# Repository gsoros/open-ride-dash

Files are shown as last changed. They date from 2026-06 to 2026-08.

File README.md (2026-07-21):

# OpenRideDash

OpenRideDash is open-source firmware for an ESP32-C3 based e-bike dashboard. It provides a compact ride display, CAN data integration, BLE and Wi-Fi connectivity, OTA updates, Shell diagnostics, and keypad-driven menus on a 240x240 ST7789 display. Currently the Bafang M560 mid-drive controller is supported.

## Features

- ESP32-C3 Super Mini support
- ST7789 240x240 color display driver
- CAN bus data integration for e-bike metrics
- BLE cycling services, API bridge for the mobile app
- Wi-Fi connectivity and OTA firmware updates
- Serial over WiFi access for diagnostics and command handling
- Custom keypad/menu navigation
- Task-based architecture for modular firmware components
- Rolling firmware bootloader support via custom bootloader replacement

## Hardware

- ESP32-C3 development board (`esp32-c3-devkitm-1`)
- ST7789 240x240 display
- CAN bus interface
- Keypad 

## Software Stack

- PlatformIO with Arduino framework
- ESP32 platform version `6.13.0`
- Arduino GFX library
- Patched MPU9250 dependency 
- `ACAN_ESP32` for CAN support
- `OneButton` for keypad/button handling

## Repository Structure

- platformio.ini — build and environment configuration
- src — main firmware source
  - main.cpp — system initialization and task startup
  - `drivers/` — display and hardware drivers
  - `model/` — shared state model
  - `tasks/` — modular runtime components (Wi-Fi, OTA, WifiSerial, CAN, display, keypad, alarm)
- include — shared headers, config, and font assets
- bootloader — bootloader binary, compiled from `esp-idf/components/esptool_py/bootloader`
- ota_nofs_4MB.csv — partition table for rollback-enabled OTA
- version, version.py, build_info.py — version/build metadata injection

## Build & Flash

1. Install PlatformIO
2. Connect the ESP32-C3 board
3. Use the `devel` environment for development builds:
   - `pio run -e devel`
   - `pio run -e devel -t upload`
4. Use `prod` for production builds
5. OTA builds are available via `develOTA` and `prodOTA`

## Notes

- `loop()` is intentionally empty; tasks are scheduled via FreeRTOS.
- The project applies a custom bootloader replacement during the build.
- The display driver uses multiple canvas layers and animated page transitions.

## Companion App

[**Wattson**](https://github.com/gsoros/wattson) is the companion mobile app for OpenRideDash. Built with Flutter, it connects to the dash via BLE to display live telemetry, record rides with GPS, and export GPX data — all local-first with no cloud dependency.

## License

This project is licensed under the terms of the included LICENSE.

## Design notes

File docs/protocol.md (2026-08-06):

# ORD Dash — BLE NUS Text API Protocol

Authoritative reference for the Nordic UART Service (NUS) command/reply protocol
used by the OpenRideDash (ORD) e-bike display.

---

## 1. Transport

### NUS Service

| Role | UUID | Property |
|---|---|---|
| NUS Service | `6e400001-b5a3-f393-e0a9-e50e24dcca9e` | — |
| RX (phone → device) | `6e400002-b5a3-f393-e0a9-e50e24dcca9e` | **WRITE** (with response) |
| TX (device → phone) | `6e400003-b5a3-f393-e0a9-e50e24dcca9e` | **NOTIFY** only (no READ) |

### RX (phone → device)

The phone writes a UTF-8 command string (max 250 bytes) to the RX characteristic.
The device processes the command asynchronously and enqueues a reply on the TX
characteristic.

### TX (device → phone) — Fragmentation

Replies are sent as one or more BLE notifications. The first notification carries
a **2-byte big-endian total-length prefix**; subsequent notifications are raw
continuation data.

```
First notification:  [len_hi][len_lo][payload bytes 0..N-1]
Subsequent:          [payload bytes N..M-1]
                     ...
```

- `len_hi` = `(total >> 8) & 0xFF`
- `len_lo` = `total & 0xFF`
- `total` = total number of payload bytes (excluding the 2-byte prefix)
- Chunk size = `min(MTU, 247) - 3` (ATT overhead). At MTU=247, each notification
  carries 244 bytes of payload.
- 10 ms delay between multi-chunk frames.

**Phone reassembly rule:** Read the first 2 bytes as big-endian total length,
then accumulate notifications until that many bytes have been received. The first
notification includes the 2-byte prefix (so first payload = `first.length - 2`).

---

## 2. Command Format

Commands are UTF-8 strings sent to the NUS RX characteristic. The format is:

```
<command>[ <args>]
```

- `<command>` — a single word (max 32 chars), case-sensitive.
- `<args>` — optional, space-delimited tokens following the command name.
- Max total length: 250 bytes (hardware limit).
- Trailing `\r` / `\n` are stripped by the device.

### Argument structure

Commands follow a consistent pattern:

| Pattern | Example |
|---|---|
| `cmd` (bare) | `hostname` — get current value |
| `cmd <value>` | `hostname ord-c3` — set value |
| `cmd <subcommand>` | `ble on`, `ble status` — subcommand action |
| `cmd <subcommand> <value>` | `wifi ssid MyNetwork` — subcommand with value |

Boolean values use the strings `on` (true) and `off` (false), as returned by
`Util::boolToString()`.

---

## 3. Reply Format

Every command produces a reply with the following wire format:

```
API [<command>[ <args>]] (<code>) <data>
```

| Part | Description |
|---|---|
| `API [` | Literal prefix |
| `<command>` | The command name (e.g. `hostname`, `ble`) |
| ` ` | Space separator (present only if args follow) |
| `<args>` | The arguments as received by the handler |
| `] (` | Literal separator |
| `<code>` | Reply code string (see below) |
| `) ` | Literal separator |
| `<data>` | Reply payload (text, may be empty) |

### Reply codes

| Code | Enum value | Meaning |
|---|---|---|
| `Success` | `Code::Success` | Command executed successfully |
| `Unknown Command` | `Code::UnknownCommand` | Command name not recognised |
| `Invalid Arguments` | `Code::InvalidArgs` | Arguments are malformed or out of range |
| `Execution Error` | `Code::ExecutionError` | Command failed at runtime |

### Examples

```
API [hostname] (Success) ord-c3
API [ble status] (Success) enabled: on, connected: true
API [wifi] (Success) sta: on, ap: on, ssid: myNetwork, password: myPassword
API [battery] (Success) 720
API [v] (Success) ord-v0.1.0-42-gabc1234
API [ble bogus] (Invalid Arguments) Usage: ble[ on|off|toggle|status]
API [nonexistent] (Unknown Command) 'nonexistent' is a mystery
```

---

## 4. Commands

### 4.1 `v` — Version

| | |
|---|---|
| **Get** | `v` |
| **Reply data** | Build info string (`whoami`) |
| **Example** | `API [v] (Success) ord-v0.1.0-42-gabc1234` |

### 4.2 `help` — Help

| | |
|---|---|
| **List** | `help` |
| **Detail** | `help <command>` |
| **Reply data (list)** | `Commands: v, help, restart, ...` |
| **Reply data (detail)** | `<command>: <helpText>` |
| **Example** | `API [help] (Success) Commands: v, help, restart, ...` |

### 4.3 `restart` — Restart

| | |
|---|---|
| **Execute** | `restart` |
| **Reply** | (never returns — device reboots immediately) |

### 4.4 `hostname` — Hostname

| | |
|---|---|
| **Get** | `hostname` |
| **Set** | `hostname <name>` |
| **Reply data (get)** | Current hostname string |
| **Reply data (set)** | New hostname string (may be trimmed) |
| **Example** | `API [hostname] (Success) ord-c3` |

### 4.5 `battery` — Battery capacity

| | |
|---|---|
| **Get** | `battery` |
| **Set** | `battery <capacity>` |
| **Args** | `<capacity>` — uint16, watt-hours |
| **Reply data (get)** | Current capacity in Wh |
| **Reply data (set)** | `Battery capacity set to <N> Wh` |
| **Example** | `API [battery] (Success) 720` |

### 4.6 `ble` — BLE radio

| | |
|---|---|
| **Status** | `ble` or `ble status` |
| **Enable** | `ble on` — **triggers reboot** |
| **Disable** | `ble off` — **triggers reboot** |
| **Toggle** | `ble toggle` — **triggers reboot** |
| **Reply data (status)** | `enabled: <on|off>, connected: <on|off>` |
| **Reply data (on/off/toggle)** | `<on|off>` — new state after applying change |
| **Example** | `API [ble] (Success) enabled: on, connected: true` |

### 4.7 `wifi` — WiFi

| | |
|---|---|
| **Summary** | `wifi` |
| **Enable STA** | `wifi on` — **triggers reboot** |
| **Disable STA** | `wifi off` — **triggers reboot** |
| **Toggle STA** | `wifi toggle` — **triggers reboot** |
| **Get SSID** | `wifi ssid` |
| **Set SSID** | `wifi ssid <name>` — restarts STA |
| **Get password** | `wifi password` |
| **Set password** | `wifi password <pw>` — restarts STA |
| **Get AP state** | `wifi ap` |
| **Enable AP** | `wifi ap on` — **triggers reboot** |
| **Disable AP** | `wifi ap off` — **triggers reboot** |
| **Toggle AP** | `wifi ap toggle` — **triggers reboot** |
| **Connection status** | `wifi status` |
| **Reply data (summary)** | `sta: <on|off>, ap: <on|off>, ssid: <name>, password: <pw>` |
| **Reply data (on/off/toggle)** | `<on|off>` — new state |
| **Reply data (ssid/password)** | Current value string |
| **Reply data (status)** | `sta: <connected|disconnected>, ap_clients: <N>` |
| **Example** | `API [wifi] (Success) sta: on, ap: on, ssid: myNetwork, password: myPassword` |

### 4.8 `sim` — Simulator (only if `FEATURE_SIM` is compiled)

| | |
|---|---|
| **Status** | `sim` |
| **Enable** | `sim on` |
| **Disable** | `sim off` |
| **Reply data** | `sim <on|off>` |
| **Example** | `API [sim] (Success) sim on` |

### 4.9 `state` — JSON telemetry snapshot

| | |
|---|---|
| **Get** | `state` |
| **Reply data** | JSON object with current telemetry values |
| **Example** | `API [state] (Success) {"speed":0.00,"pas":0,"torque":750,...}` |

### 4.10 `echo` — WifiSerial echo (only if WifiSerial is active)

| | |
|---|---|
| **Enable** | `echo on` |
| **Disable** | `echo off` |
| **Reply data** | `WifiSerial echo <on|off>` |

### 4.11 `key` — Simulate key press

| | |
|---|---|
| **Execute** | `key <up|down|upLong|downLong|power|menu>` |
| **Reply** | (triggers UI event, no meaningful data) |

### 4.12 `arm` / `disarm` — Motion alarm

| | |
|---|---|
| **Arm** | `arm` |
| **Disarm** | `disarm` |
| **Reply** | (arms/disarms MPU motion sensor) |

### 4.13 `nullpointer` — Crash test

| | |
|---|---|
| **Execute** | `nullpointer` |
| **Reply** | (crashes the device intentionally) |

### 4.14 `torquelog` — Torque sensor ring buffer dump

| | |
|---|---|
| **Get** | `torquelog` |
| **Reply data** | Header line + up to 20 torque samples |
| **Example** | `API [torquelog] (Success) torquelog: 154 samples` then `T:12345 R:1250 O:500 C:80 S:5 ST:5B U2:0\n...` |

Dumps the most recent torque sensor samples from the internal ring buffer.
Each sample line format: `T:<timestamp_ms> R:<rawTorque> O:<offsetTorque> C:<cadence> S:<sequence> ST:<status> U2:<unknown2>`.
Always present (no feature flag needed).

### 4.15 `ema` — EMA smoothing bypass

| | |
|---|---|
| **Status** | `ema` |
| **Enable** | `ema on` |
| **Disable** | `ema off` |
| **Reply data** | `ema <on|off>` |
| **Example** | `API [ema] (Success) ema on` |

Controls the exponential moving average filters applied to human power, SoC,
and range. When OFF, raw (unfiltered) values are returned, making torque drops
easier to detect. Always present.

---

## 5. Boolean representation

All boolean values use the strings `on` (true) and `off` (false), as defined by
`Util::boolToString()`:

```cpp
static const char* boolToString(bool value) {
    return value ? "on" : "off";
}
```

Parsing helpers:

```cpp
static bool isStrBoolOn(const char* str)  { return strcmp(str, "on") == 0; }
static bool isStrBoolOff(const char* str) { return strcmp(str, "off") == 0; }
static bool parseBoolValue(const char* args, bool* value);
```

---

## 6. CTS Telemetry Payload

The CTS custom service (`f6333d96-74c0-462d-b92d-5750a2283429`) sends a 14-byte
little-endian binary payload on the telemetry characteristic
(`5ee460d2-75a3-41ac-9034-2b2d435bb549`, NOTIFY + READ).

| Byte | Field | Type | Scale |
|---|---|---|---|
| 0 | Version/flags | `uint8` | `0x01` |
| 1–2 | Speed | `uint16` LE | km/h × 100 |
| 3–4 | Battery voltage | `uint16` LE | V × 100 |
| 5–6 | Battery current | `uint16` LE | A × 100 (unsigned — no regen) |
| 7 | State of charge | `uint8` | % |
| 8–9 | Range | `uint16` LE | km × 100 |
| 10 | PAS level | `int8` | −1 walk, 0 off, 1–5 |
| 11–12 | Human power | `uint16` LE | W × 10 |
| 13 | Cadence | `uint8` | RPM |

Forward-compat: ignore trailing bytes if `length > 14`; reject unknown version.

---

## 7. CTS HR Write Characteristic

The CTS service also exposes a write characteristic for receiving heart rate data
from the phone:

| UUID | Property | Payload |
|---|---|---|
| `a2c4f7b1-0e3d-4a8c-9b6e-1f2c3d4e5f60` | **WRITE_NR** | Single `uint8` BPM |

The phone writes the current heart rate (BPM) from a connected BLE HRM. The
device stores it in `state.heartRate()` and surfaces it on the display.

---

## 8. Consistency notes

- **Every command** follows the pattern `cmd[ subcmd][ value]`.
- **Every reply** uses the fixed wire format `API [<cmd> <args>] (<code>) <data>`.
- **Every boolean** in reply data uses `on`/`off` from `Util::boolToString()`.
- **Set commands** that change a value return the new value in the reply data.
- **Get commands** (bare command, no args) return the current value.
- **Reboot-triggering commands** (`ble on|off|toggle`, `wifi on|off|toggle`,
  `wifi ap on|off|toggle`) never return a reply — the device restarts immediately.

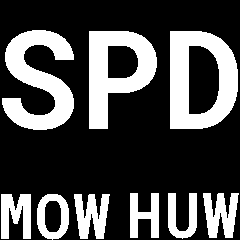
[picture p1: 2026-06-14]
include/display_mockup/metrics_labels_speed-motorPower-human_power.png

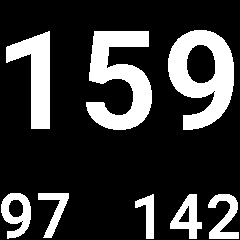
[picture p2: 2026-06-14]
include/display_mockup/metrics_values_heartRate-SOC-range.png

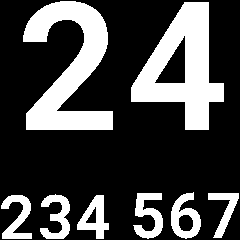
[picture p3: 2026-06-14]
include/display_mockup/metrics_values_speed-motorPower-humanPower.png

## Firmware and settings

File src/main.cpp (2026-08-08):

#include <Arduino.h>

#include "config.h"
#include "model/state.h"
#include "tasks/wifi.h"
#include "tasks/ota.h"
#include "tasks/wifiserial.h"
#include "tasks/system_monitor.h"
#include "tasks/api.h"
#include "tasks/ble.h"
#include "tasks/display.h"
#ifdef FEATURE_SIM
#include "tasks/sim.h"
#endif
#include "tasks/can.h"
#include "tasks/keypad.h"
#include "tasks/alarm.h"

State state;
Api api;
Ble ble;
#ifdef FEATURE_SIM
Sim sim;
#endif
CAN can;
Display display;
Wifi wifi;
OTA ota;
WifiSerial wifiSerial(23);
SystemMonitor systemMonitor;
Keypad keypad;
Alarm alarmTask;  // 'alarm' is a reserved word

void setup() {
    esp_log_level_set("*", ESP_LOG_DEBUG);
    ulong t = millis();

#ifdef FEATURE_SERIAL
    Serial.setTxTimeoutMs(0);
    Serial.setDebugOutput(false);
    Serial.begin(115200);
    while (!Serial && millis() - t < 100) delay(10);
    // delay(100);
#endif

    state.setup();

    api.setup();
    api.taskStart(10.0f, 4096 + 512 + 512);

    ble.setup();
    ble.taskStart(5.0f, 4096);  // Telemetry and Battery updates are rate-limited to 1 Hz, BLEDebug is rate-limited to 20 Hz (50ms)

    display.setup();
    display.taskStart(50.0f, 2048 + 1024 + 512);

    wifi.setup();
    wifi.taskStart(1.0f, 8192);  // AP mode does not work with lower stack size
    wifi.waitForReady();

    if (wifi.isEnabled()) {
        ota.setup();
        ota.taskStart(2.0f, 100.0f, 2048 + 1024 + 512 + 512);
    }

    wifiSerial.setup(wifi.isEnabled());
    wifiSerial.taskStart(10.0f, 1024 + 512 + 512);

#ifdef FEATURE_SIM
    sim.setup();
    sim.taskStart(2.0f, 1024);
#endif

    can.setup();
    can.taskStart(100.0f, 2048 + 512);

    keypad.setup();
    keypad.taskStart(100.0f, 1024 + 512 + 512);

    alarmTask.setup();
    alarmTask.taskStart(100.0f, 1024 + 512 + 512);

    // static Task* tasksToMonitor[] = {&api, &wifi, &ota, &wifiSerial, &display, &can};
    // systemMonitor.setup(tasksToMonitor, sizeof(tasksToMonitor) / sizeof(tasksToMonitor[0]));
    // systemMonitor.taskStart(10.0f, 4096);
}

void loop() {
    vTaskDelete(nullptr);
}

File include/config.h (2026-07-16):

#ifndef CONFIG_H
#define CONFIG_H

#define STR_HELPER(x) #x
#define STR(x) STR_HELPER(x)

#if ORD_BOARD == c3_supermini
#include "pins_c3_supermini.h"
#else
#error "Unsupported board. Please define ORD_BOARD in platformio.ini"
#endif

constexpr const char* DEFAULT_WIFI_SSID = "myNetwork";        // STA SSID
constexpr const char* DEFAULT_WIFI_PASSWORD = "myPassword";   // STA password
constexpr const char* DEFAULT_WIFI_AP_SSID = "OpenRideDash";  // AP SSID

// Fallback AP: if STA doesn't connect within this time, start a passwordless AP
constexpr unsigned long WIFI_STA_TIMEOUT_MS = 60000;
constexpr unsigned char WIFI_AP_CHANNEL = 1;
constexpr unsigned char WIFI_AP_MAX_CONNECTIONS = 2;

#ifndef ORD_NAME
// keep the format, build_info.py will parse this
#define ORD_NAME "OpenRideDash"
#endif

#ifndef ORD_SHORT_NAME
// keep the format, build_info.py will parse this
#define ORD_SHORT_NAME "ord"
#endif

#ifdef BUILDTAG
constexpr const char* DEFAULT_HOSTNAME = ORD_SHORT_NAME "-" STR(BUILDTAG);
#else
constexpr const char* DEFAULT_HOSTNAME = ORD_SHORT_NAME;
#endif

#ifndef TFT_ROTATION
#define TFT_ROTATION 3
#endif

// ST7789 column/row offsets used by Arduino_GFX/Arduino_TFT.
// These are panel/module specific and can be adjusted per module.
// Format: COL_OFFSET1, ROW_OFFSET1, COL_OFFSET2, ROW_OFFSET2
// Defaults are set to values known to work with the maintainer's module.
#ifndef ST7789_COL_OFFSET1
#define ST7789_COL_OFFSET1 0
#endif

#ifndef ST7789_ROW_OFFSET1
#define ST7789_ROW_OFFSET1 0
#endif

#ifndef ST7789_COL_OFFSET2
#define ST7789_COL_OFFSET2 0
#endif

#ifndef ST7789_ROW_OFFSET2
#define ST7789_ROW_OFFSET2 80
#endif

#endif  // CONFIG_H

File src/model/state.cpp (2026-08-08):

#include "state.h"
#include "tasks/api.h"
#include "config.h"
#include "util.h"
#include "util/ema.h"

#include <freertos/FreeRTOS.h>
#include <freertos/semphr.h>

#ifdef FEATURE_SIM
#include "tasks/sim.h"
extern Sim sim;  // for sim.isEnabled()
#endif

// File-scope EMA instances for human power, SoC, and range filtering.
// Replaces the earlier static locals inside each method.
static Ema g_humanPowerEma(0.2f);
static Ema g_socEma(0.1f);
static Ema g_rangeEma(0.1f);
static bool g_emaDisabled = true;  // default to disabled until explicitly enabled via API command

float State::Snapshot::speed() {
    return (float)speed_x100 / 100.0f;
}

float State::Snapshot::motorPower() {
    float current = (float)batteryCurrent_x100 / 100.0f;
    float voltage = (float)batteryVoltage_x100 / 100.0f;
    float power = current * voltage;

    /*
    static uint32_t lastLog = 0;
    if (millis() - lastLog > 1000) {
        ESP_LOGD(tag, "motorPower() Current: %.1f, Voltage: %.1f, Power: %.1f", current, voltage, power);
        lastLog = millis();
    }
    */
    return power;
}

float State::Snapshot::humanPower() {
    // power (W) = cadence (RPM) * torque (Nm) * 2 * pi / 60
    float power = (float)cadence * (float)(torque + TORQUE_OFFSET) / TORQUE_NM_FACTOR * 0.104719755f;

    // Log while debugging the mysterious "power" bug, unless sim is enabled
    static bool shouldLog = true;
#ifdef FEATURE_SIM
    if (sim.isEnabled()) shouldLog = false;
#endif
    if (shouldLog) {
        static float lastPower = 0.0f;
        if (lastPower != power) {
            ESP_LOGD(tag, "humanPower() Cadence: %u, Torque: %u, Power: %.1f", cadence, torque, power);
            lastPower = power;
        }
    }

    // Simple exponential moving average
    float filtered = g_humanPowerEma.filter(power);

    return g_emaDisabled ? power : filtered;
}

float State::Snapshot::soc() {
    constexpr float sagFactor = 0.003f;  // Vcell/Apack (10A → 0.03V sag)
    float soc = -1.0f;

    // INR21700-50E discharge curve: {voltage, soc%}
    // Derived from typical 0.2C discharge curve, 3.3–4.2V range
    constexpr float curve[][2] = {
        {4.20f, 100.0f},  // surface charge effect, cell "relaxes" after a full charge top-up
        {4.10f, 100.0f},  // flat — no interpolation artifact, just 100% across the top
        {4.05f, 85.0f},
        {4.00f, 79.0f},
        {3.95f, 73.0f},
        {3.90f, 67.0f},
        {3.85f, 61.0f},
        {3.80f, 55.0f},
        {3.75f, 49.0f},
        {3.70f, 43.0f},
        {3.65f, 36.0f},
        {3.60f, 28.0f},
        {3.55f, 20.0f},
        {3.50f, 13.0f},
        {3.45f, 7.0f},
        {3.40f, 3.0f},
        {3.35f, 1.0f},
        {3.30f, 0.0f},
    };
    constexpr size_t curveLen = sizeof(curve) / sizeof(curve[0]);

    float packVoltage = (float)batteryVoltage_x100 / 100.0f;
    float current = (float)batteryCurrent_x100 / 100.0f;

    // Compensate for voltage sag: estimate open-circuit voltage
    float cellVoltage = (packVoltage / BATTERY_PACK_CELL_COUNT) + (current * sagFactor);

    // Clamp to curve bounds
    if (soc < 0.0f && cellVoltage >= curve[0][0]) soc = curve[0][1];
    if (soc < 0.0f && cellVoltage <= curve[curveLen - 1][0]) soc = curve[curveLen - 1][1];

    // Linear interpolation between curve points
    if (soc < 0.0f) {
        for (size_t i = 0; i < curveLen - 1; i++) {
            float vHi = curve[i][0];
            float vLo = curve[i + 1][0];
            if (cellVoltage <= vHi && cellVoltage >= vLo) {
                float t = (cellVoltage - vLo) / (vHi - vLo);
                soc = curve[i + 1][1] + t * (curve[i][1] - curve[i + 1][1]);
            }
        }
    }

    // Simple exponential moving average
    float filtered = g_socEma.filter(soc);

    /*
    static uint32_t lastLog = 0;
    if (millis() - lastLog > 1000) {
        ESP_LOGD(tag, "soc() Cell voltage: %.3f, SOC: %.1f%%", cellVoltage, filtered);
        lastLog = millis();
    }
    */

    float result = filtered < 0.0f ? 0.0f :  // clamp to 0-100%
                       filtered > 100.0f ? 100.0f
                                         : filtered;
    return g_emaDisabled ? soc : result;
}

float State::Snapshot::range() {
    float speed_kmph = speed();
    float soc_pct = soc();
    float humanP_W = humanPower();
    float motorP_W = motorPower();
    float rawRange = -1.0f;

    if (rawRange < 0.0f && (speed_kmph < 0.5f || motorP_W <= 0.0f))
        rawRange = 0.0f;

    float remainingEnergy_Wh = batteryCapacity * (soc_pct / 100.0f);
    float motorEfficiency_WhPerKm = motorP_W / speed_kmph;

    if (motorEfficiency_WhPerKm > 50.0f || motorEfficiency_WhPerKm < 0.5f)
        rawRange = 0.0f;

    if (rawRange < 0.0f)
        rawRange = remainingEnergy_Wh / motorEfficiency_WhPerKm;

    // Simple exponential moving average
    float filteredRange = g_rangeEma.filter(rawRange);

    /*
    static uint32_t lastLog = 0;
    if (millis() - lastLog > 1000) {
        ESP_LOGD(tag,
                 "range() Speed: %.1f km/h, Motor: %.1f W, Human: %.1f W, "
                 "Energy: %.1f Wh, Raw: %.1f km, Filtered: %.1f km",
                 speed_kmph, motorP_W, humanP_W, remainingEnergy_Wh,
                 rawRange, filteredRange);
        lastLog = millis();
    }
    */

    return g_emaDisabled ? rawRange : filteredRange;
}

State::State() {
    mutex = xSemaphoreCreateMutex();
}

void State::setup() {
    if (!preferencesSetup("state"))
        ESP_LOGE(tag, "preferencesSetup() failed");
    if (!restoreFromPreferences())
        ESP_LOGE(tag, "restoreFromPreferences() failed");
    registerApiCommands();
    ESP_LOGD(tag, "Initialized");
}

bool State::restoreFromPreferences() {
    if (!preferencesReady) {
        ESP_LOGE(tag, "restoreFromPreferences() preferences not ready");
        return false;
    }
    uint16_t capacity = (uint16_t)preferences.getUInt("batteryCapacity", DEFAULT_BATTERY_CAPACITY);
    ESP_LOGD(tag, "restoreFromPreferences() batteryCapacity: %u", capacity);
    if (capacity < 10 || capacity > 10000) {
        ESP_LOGW(tag, "restoreFromPreferences() batteryCapacity out of range, using default %u", DEFAULT_BATTERY_CAPACITY);
        capacity = DEFAULT_BATTERY_CAPACITY;
    }
    batteryCapacity(capacity, false);

    String storedHostname = preferences.getString("hostname", DEFAULT_HOSTNAME);
    hostname(storedHostname.c_str());
    ESP_LOGD(tag, "restoreFromPreferences() hostname: %s", _latest.hostname);

    return true;
}
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

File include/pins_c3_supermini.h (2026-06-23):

#define PIN_ONBOARD_LED 8  // used in blink.h

#define PIN_KEY_UP 10
#define PIN_KEY_DOWN 20
#define PIN_KEY_POWER 21

#define PIN_I2C_SDA 5
#define PIN_I2C_SCL 9
#define PIN_MPU_INT 3

#define PIN_SPI_SCK 6
#define PIN_SPI_MOSI 7
#define PIN_TFT_DC 4
#define PIN_TFT_RST 8
#define PIN_TFT_CS -1  // NC
#define PIN_TFT_BL 2

#define PIN_CAN_RX 0
#define PIN_CAN_TX 1

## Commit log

2026-04-01 Refine Phase 1 documentation with updated hardware specifications, assembly instructions, and additional circuit details for controller power management
2026-04-02 Update Phase 1 documentation with revised hardware components, detailed controller power management, and additional assembly instructions
2026-04-03 Update hardware architecture and documentation for OpenRideDash
    - Changed display from SSD1283A to ST7789 in hardware architecture and related documentation.
    - Updated CAN transceiver from TJA1050 to SN65HVD230 across all relevant files.
    - Modified build flags in configuration files to reflect new display and transceiver.
    - Adjusted assembly instructions and component lists to match updated hardware specifications.
    - Revised FAQ and troubleshooting sections to align with new components.
    - Removed obsolete plan.md file as it is no longer needed.
2026-04-03 Update protections section for 48V system in Phase 1 documentation
2026-04-06 Delete Controller Power-On section from phase1-core.md
    Removed the powerOnController function from documentation.
2026-05-13 Add schematic and .gitignore
    [ord-v0.1.kicad_sch]
2026-05-15 Update schematic
    [ord-v0.1.kicad_sch]
2026-05-15 Enhance WiFi connectivity and logging features in main.cpp; update platformio.ini for board configuration
    [ord-v0.1.kicad_sch]
2026-05-18 Refactor task management: remove LogServer, add Telnet and SystemMonitor tasks; enhance API functionality and task setup methods
    [ord-v0.1.kicad_sch]
2026-05-19 Add display driver and integrate with Blink task
    - Introduced DisplayDriver interface and ST7789 implementation for display management.
    - Updated Blink task to use ONBOARD_LED instead of LED.
    - Added Display task to manage display output and text rendering.
    - Updated platformio.ini to include necessary Adafruit libraries.
2026-05-19 Refactor display driver: update brightness method and adjust display setup in tasks
    [ord-v0.1.kicad_sch]
2026-05-19 Refactor ST7789 driver: replace Adafruit libraries with TFT_eSPI, update initialization and drawing methods, and add user setup configuration
    [st7789.h]
2026-05-20 Enhance ST7789 driver configuration, add brightness control to display tasks, and implement system restart command in API
    [ord-v0.1.kicad_sch]
2026-05-20 Refactor ST7789 driver
2026-05-21 Use forked TFT_eSPI lib with SPI fix until PR is merged
    [display.h]
2026-05-21 Refactor display driver to use Arduino_GFX library, update configuration, and enhance ST7789 initialization
2026-05-27 Switched back to core v2.x for smaller flash size. Optimized partition layout. Separated canvases. Added power sim.
    [ota_nofs_4MB.csv]
2026-05-28 Revised GPIO mapping, added serial input to api (in telnet task for now).
    [ord-v0.1.kicad_sch]
2026-05-28 Added keypad support
    [ord-v0.1.kicad_sch]
2026-05-29 CAN experiments
    [ord-v0.1.kicad_sch]
2026-05-29 Updated state data structure, added CAN processing
    [ord-v0.1.kicad_sch]
2026-05-29 Keypad interrupts, display updates, state changes.
2026-05-30 Test keypad polling instead of interrupts using the OneButton library
2026-05-30 More CAN frame parsing
2026-06-14 Prompt for page switching and menu
2026-06-14 Page switching with spatial Bayer ordered-dither blend!
2026-06-14 split display driver
2026-06-16 switched from GFX to U8G2 fonts
2026-06-17 added EMA filters
2026-06-18 fixed menu exit bug, added menu refactor TODO
    [st7789_240x240.cpp]
2026-06-23 rename pin macros, prepare alarm class split
2026-06-25 add NC keypad wires to schematic
    [ord-v0.1.kicad_sch]
2026-06-26 bug fixes and improvements
    [config.h, display.h, st7789_240x240.cpp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]
2026-06-26 Enhance ST7789 display driver with logging and mode string conversion; improve state management for PAS levels
2026-06-29 Refactor ST7789 display driver: implement constructor, enhance feedback handling, and improve logging; update display modes and transition logic
2026-06-30 Update font generation commands and enhance ST7789 display driver: include capital P glyph in large font, adjust torque calculation, and improve comments for clarity
2026-07-02 Update ST7789 display driver to use configurable column/row offsets and adjust TFT rotation
2026-07-04 Update battery current scaling factor
2026-07-05 Optimize CAN state updates, fix typo in mutex function name, and improve log messages
    [state.cpp, state.h]
2026-07-10 Refactor speed and torque variables in State class; update CAN message parsing and logging
2026-07-10 Refactor metric units in ST7789_240x240 display driver for consistency
2026-07-11 Refactor State and Menu classes for improved clarity; replace magic numbers with named constants and streamline menu item handling
    [display.h, state.h]
2026-07-11 add Canvas wrapper class for Arduino_Canvas_Mono, add simple splash
2026-07-11 fix(st7789_240x240): adjust splash screen text positioning
    [st7789_240x240.cpp]
2026-07-12 fix(st7789_240x240): disable text wrapping for canvas objects in setup
    [st7789_240x240.cpp]
2026-07-12 fix(state): update wheel size handling and logging format
    [state.cpp, state.h]
2026-07-15 fix(api): suppress \r echo and adjust reply line break
    [api.cpp]
2026-07-16 refactor(display): use driver factory and screen state machine
2026-07-17 fix(ble): correct device info and advertising appearance
2026-07-18 feat(sim): prevent sleep when simulation is active
    [alarm.cpp, sim.h]
2026-07-19 fix(sim): guard sim references with FEATURE_SIM
    [main.cpp, sim.h, st7789_240x240.cpp]
2026-07-19 feat(sim): simulate human power, cadence, and torque
2026-07-19 feat(sim): simulate battery drain based on motor power
2026-07-19 feat(sim): simulate PAS level based on motor power
2026-07-19 fix(display): route nextPage requests through UI event queue instead of sync SPI DMA access
    [display.cpp, st7789_240x240.cpp]
2026-07-19 docs(can): add TODO to investigate torque reading drops
2026-08-06 feat(ble): add debug service, torquelog command, and EMA filter control
2026-08-07 fix(task): streamline memory usage
    [can.cpp, main.cpp]
2026-08-08 feat: disable EMA by default and remove torque ring buffer
    - Set EMA default to disabled, requiring explicit API command to enable.
    - Remove torque sample ring buffer and "torquelog" command to save memory.
    - Add debug logging for parsed torque/cadence via FEATURE_DEBUG_BLE.
    - Disable duplicate printf in debugLog to avoid double UART output.
    [can.cpp, state.cpp]
2026-08-08 refactor(ble): rename cycling services to telemetry, add rate limiting constant
    - Rename updateCyclingServices to updateTelemetryServices and related variables for clarity.
    - Introduce kTelemetryTickMs constant (1000 ms) for telemetry update interval.
    - Add null check for CTS characteristic in updateTelemetryServices.
    - Improve battery level update: add early null checks, rate limit to 1 Hz, skip if unchanged.
    - Fix debug log buffer size calculation using sizeof(entry.message) instead of magic number.
    - Adjust BLE task frequency to 5 Hz to accommodate debug logging rate.
    [ble.h, main.cpp]
2026-08-08 fix(can): correct torque drop detection and mutex handling
    [can.cpp]
2026-08-13 fix(can): refine 0x02F83200 frame parsing and logging
    - Update byte mapping based on new field insights
    - Expand sequence to 2-byte value for better monotonicity tracking
    - Remove stale/duplicate torque filtering, add discard logging
    - Restructure debug output for clarity and BLE integration
    [can.cpp]
2026-08-14 refactor(can, debug_log): replace formatted debugLog with stack-light debugLogRaw in hot paths
    [can.cpp]
